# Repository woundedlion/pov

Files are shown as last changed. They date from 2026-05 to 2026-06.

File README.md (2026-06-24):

# Holosphere

### [▶ Play with the live WebAssembly simulator](https://woundedlion.github.io/daydream/)

### [📖 API documentation (Doxygen)](https://woundedlion.github.io/pov/)

---

<p align="center">
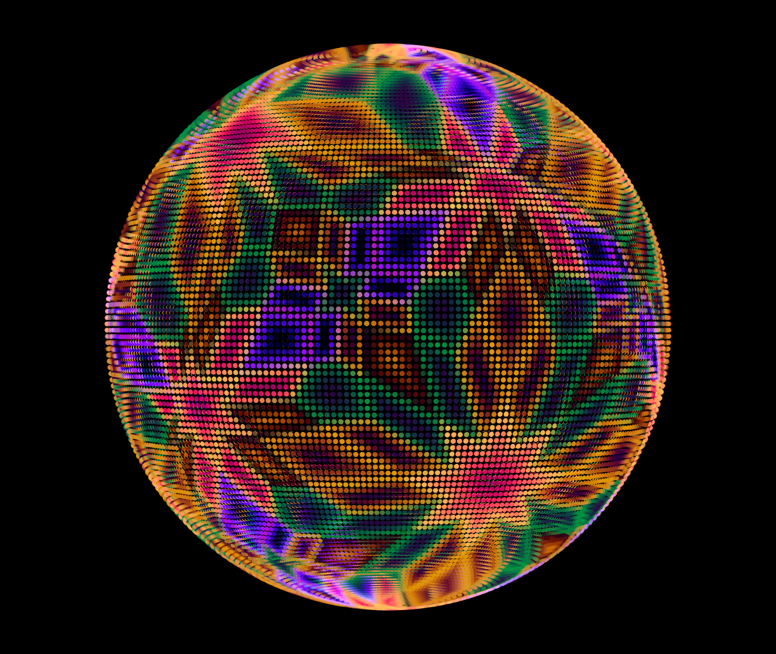
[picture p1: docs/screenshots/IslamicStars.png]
Holosphere — IslamicStars effect
  
</p>

A persistence-of-vision (POV) LED sphere and its real-time simulator. The device spins a strip of LEDs at 480 RPM while a Teensy microcontroller fires pixels at microsecond intervals to paint full-color imagery on the surface of a virtual sphere. The simulator renders the same effects in a browser window at up to 288×144 resolution using the identical C++ code compiled to WebAssembly.

The project spans **two repositories** that ship as one product:

| Repo | Role | What lives here |
|---|---|---|
| [**Holosphere**](https://github.com/woundedlion/pov) | C++ engine + firmware | All rendering code, effects, hardware drivers (`pov_single.h`, `pov_segmented.h`), the Emscripten/WASM target, unit tests, and this README. |
| [**daydream**](https://github.com/woundedlion/daydream) | Web simulator | Three.js renderer, the compiled `holosphere_wasm.{js,wasm}` artifacts (output of Holosphere's WASM build), GUI/sidebar, recorder, segmented-POV Web Workers, and standalone geometry tools. |

Building the WASM target in Holosphere installs `holosphere_wasm.js`, `holosphere_wasm.wasm`, this README, and `docs/screenshots/` into the sibling `daydream/` checkout — so both repos always serve the same README. The live demo is daydream served from GitHub Pages.

---

## Table of Contents

1. [Hardware](#1-hardware)
2. [Engineering Philosophies](#2-engineering-philosophies)
3. [Repository Map](#3-repository-map)
4. [Architecture Overview](#4-architecture-overview)
5. [Data Flow: Frame Lifecycle](#5-data-flow-frame-lifecycle)
6. [The Rendering Pipeline](#6-the-rendering-pipeline)
   - [End-to-End Flow](#end-to-end-flow)
   - [Pipeline Domain Transitions](#pipeline-domain-transitions)
   - [The Canvas](#the-canvas)
   - [The Filter Pipeline](#the-filter-pipeline)
7. [Core Subsystems](#7-core-subsystems)
   - [7.0 The Shader Interface](#70-the-shader-interface)
   - [7.1 SDF Shapes and the Scan Rasterizer](#71-sdf-shapes-sdfh-and-the-scan-rasterizer-scanh)
   - [7.2 The Curve Rasterizer](#72-the-curve-rasterizer-ploth)
   - [7.3 The Animation System](#73-the-animation-system-animationh)
   - [7.4 Geometry Transformers](#74-geometry-transformers-transformersh)
   - [7.5 Memory Architecture](#75-memory-architecture-memoryh-memorycpp)
   - [7.6 The Color System](#76-the-color-system-colorh)
   - [7.7 The Mesh System](#77-the-mesh-system-meshh-conwayh-hankinh-spatialh-solidsh)
   - [7.8 Generators](#78-generators-generatorsh)
   - [7.9 The Preset System](#79-the-preset-system-presetsh)
   - [7.10 Hardware Drivers](#710-hardware-drivers-dma_ledh-pov_singleh-pov_segmentedh)
     - [Frame Sync Protocol: 1-Wire Signal Datasheet](#frame-sync-protocol-1-wire-signal-datasheet)
8. [The Effect System](#8-the-effect-system)
9. [Effects Reference](#9-effects-reference)
10. [The Web Simulator (Daydream)](#10-the-web-simulator-daydream)
    - [10.1 Process and Threading Model](#101-process-and-threading-model)
    - [10.2 The WASM Bridge](#102-the-wasm-bridge)
    - [10.3 The Three.js Renderer](#103-the-threejs-renderer-driverjs)
    - [10.4 Application State](#104-application-state-statejs)
    - [10.5 The Effect Sidebar](#105-the-effect-sidebar-sidebarjs)
    - [10.6 GUI Auto-Generation](#106-gui-auto-generation)
    - [10.7 Segmented POV Workers](#107-segmented-pov-workers-segment_workerjs)
    - [10.8 Vendor Importmap](#108-vendor-importmap-local-first--cdn-fallback)
    - [10.9 Video Recording](#109-video-recording-recorderjs)
    - [10.10 Resolution Presets](#1010-resolution-presets)
    - [10.11 Geometry Tools](#1011-geometry-tools-daydreamtools)
11. [Building](#11-building)

---

## 1. Hardware

Two physical targets share the same rendering engine:

### Holosphere (2015)

| Component | Detail |
|---|---|
| Controller | Teensy 4.0 (600 MHz ARM Cortex-M7) |
| LEDs | 40-pixel addressable strip (20 per half-arm, two-arm rotation) |
| Protocol | SPI via FastLED (WS2801 at 6 MHz) or DMA (HD107S at 12 MHz) |
| Rotation | 480 RPM (8 revolutions/second) |
| Virtual resolution | 96 × 20 |
| Driver | `POVDisplay<40, 480>` in `pov_single.h` |
| Pin assignments | DATA: pin 11, CLOCK: pin 13, RANDOM seed: analog pin 15 |

### Phantasm

| Component | Detail |
|---|---|
| Controllers | 4× Teensy 4.0 (600 MHz ARM Cortex-M7) |
| LEDs | 2 × 144-pixel strips (288 total, 72 per segment) |
| Protocol | DMA (HD107S at 24 MHz) |
| Rotation | 480 RPM (8 revolutions/second), 16 FPS from 2 sides of the ring |
| Virtual resolution | 288 × 144 |
| Driver | `POVSegmented<288, 4, 480>` in `pov_segmented.h` |
| Synchronization | 1-wire: count-coded sync symbols from segment 0 discipline a per-board flywheel timebase (`hardware/pov_sync.h`) |
| Pin assignments | ID: pins 21–22, Sync symbols: pin 3 (out, segment 0) / pin 4 (in), SPI: pins 11 + 13 |

The POV effect works because each revolution takes ~125 ms and a new column is painted every `1,000,000 / (RPM/60) / width` microseconds (on Holosphere the IntervalTimer ISR advances one column per fire; on Phantasm each board's flywheel ISR derives the column from the CPU cycle counter — see §7.10). The LED strip is mounted on both sides of a rotating arm: the top half of the strip handles one hemisphere and the bottom half handles the opposite hemisphere, so one full revolution paints a complete sphere.

---

## 2. Engineering Philosophies

The five design decisions below account for much of the engine's structure; the rest of the document assumes them.

### Why 16-bit Linear Color?

Most LED art codebases use gamma-corrected 8-bit values throughout and blend in sRGB space. This produces muddy mixes: red + blue = dark purple instead of magenta. Holosphere blends in linear light (16-bit precision), then gamma-encodes only at the hardware output. The improvement is most visible in soft gradients and multi-layer alpha compositing. Palette interpolation goes a step further into the OKLCH perceptual color space, with shortest-arc hue interpolation that avoids the red→green→blue detour.

### Why Compile-Time Resolution?

Templating on `<W, H>` means every pixel coordinate transform, bounding box computation, and LUT index is resolved at compile time. The hardware target `<96, 20>` runs with no runtime overhead from generality. The simulator builds separate specializations for `<288, 144>`. Each supported resolution is a separate instantiation, so binary size increases in exchange.

### Why Arena Allocation?

The Teensy heap fragments under heavy mesh subdivision. The single-block partitioned arena design (persistent + scratch A + scratch B, 335 KB total) gives deterministic memory behavior: persistent data allocated once and kept; scratch data RAII-scoped to the function that needed it. The `configure_arenas()` function allows effects to repartition the fixed block based on their needs — mesh-heavy effects can claim more persistent space, while subdivision-heavy effects can expand their scratch pools. All functions take explicit `Arena&` parameters — Conway operators take `(Arena& target, Arena& temp)`, generators take `(Arena& a, Arena& b)` — so the memory layout during heavy geometric operations is explicit at every call site, with no hidden state or implicit arena references.

### Why the ISR Double Buffer?

POV display requires pixel data to be ready before each column interval fires — roughly 434 µs to 1.3 ms depending on resolution at 480 RPM (the per-column period is `1,000,000 / (RPM/60) / W` µs, i.e. ~434 µs for Phantasm's 288 columns and ~1302 µs for Holosphere's 96). A naive approach (rendering in the ISR) would block the main loop. Instead, the main loop renders freely into a back buffer while the ISR reads from a separate front buffer. `queue_frame()` / `advance_display()` synchronize with minimal interrupt-disabled critical sections.

### Why Fail-Fast (`HS_CHECK`)?

On hardware there is no debugger attached and no console to read — a corrupted arena that ships garbage to the LEDs is the worst possible outcome, because the failure is silent and the cause is already gone by the time it shows on the sphere. So invariant violations *trap at the violation site* rather than being masked by bounded fallbacks. `HS_CHECK(cond)` (`platform.h`) compiles to a single predicted-not-taken branch to `__builtin_trap()` and, unlike `assert()`, is **not** stripped by `NDEBUG` — it still fires in the optimized device build, where `NDEBUG` is defined only to keep newlib's `__assert_func`→`fprintf` (and all of stdio) out of the image. It pulls in no stdio of its own.

The rule is deliberate about *where* it goes: `HS_CHECK` guards **cold** paths only — container growth, arena OOM, capacity and bounds guards at allocation/registration/config seams — where a violation is a logic or sizing bug with no valid recovery. It is never placed in the per-pixel hot loop; hot paths that need a check use a stripped `assert` backed by a cold trap at the corresponding bind/setup site. Genuinely *transient* conditions (a DMA overrun, a dropped frame) are not invariant violations and get bounded/soft handling instead. The native test suite includes a death harness that asserts these traps actually fire (`SIGILL` / `STATUS_ILLEGAL_INSTRUCTION`), so the safety net is verified rather than assumed.

### Coordinate Conventions

- **Y-up Cartesian**: `Vector(x, y, z)` — `y` is the vertical axis
- **Spherical**: `theta` = azimuth (longitude), `phi` = polar angle from +Y (co-latitude)
- **Pixel mapping**: `x ∈ [0, W)` → `theta ∈ [0, 2π)`, `y ∈ [0, H)` → `phi ∈ [0, π]`
- **SDF distances**: in radians on the unit sphere (matching `angle_between()`)
- All geometry LUTs (`PhiLUT<H>`, `TrigLUT<W,H>`) are pre-computed eagerly via `init_geometry_luts()` at engine setup

```
   Side view (looking down −Z):          Top view (looking down −Y):

         +Y (φ=0, north pole)                   +Z (θ=π/2)
          │                                      │
          │  ╱ point P                           │
          │ ╱φ                                   │  ╱ point P
          │╱                                    │ ╱θ
  ────────●────────  equator (φ=π/2)    ────────●────────  +X (θ=0)
          │                                      │
          │                                      │
         −Y (φ=π, south pole)                   −Z (θ=3π/2)

   Pixel canvas → sphere:
      x ∈ [0, W)  →  θ ∈ [0, 2π)    column wraps around the equator (x=0 at +X)
      y ∈ [0, H)  →  φ ∈ [0, π]     row descends from north pole (y=0) to south pole
```

---

## 3. Repository Map

### Holosphere (engine + firmware)

```
├── core/                       Rendering engine
│   ├── platform.h              Arduino vs. WASM vs. Desktop abstraction layer
│   ├── constants.h             MAX_W, MAX_H + ClipRegion segment clip rectangle
│   ├── canvas.h                Effect base class + Canvas RAII write-buffer guard
│   ├── engine.h                Engine API umbrella — included by every effect
│   ├── effects.h               Effect roster (includes each effect + HS_EFFECT_LIST)
│   ├── effects_legacy.h        Pre-engine effects (TheMatrix, Spirals, etc.)
│   ├── effect_registry.h       Self-registering factory: REGISTER_EFFECT macro
│   ├── led.h                   LED pin constants + color-correction RAII guards (driver in hardware/pov_single.h)
│   │
│   ├── 3dmath.h                Vector, Quaternion, Spherical, Complex, Möbius math
│   ├── geometry.h              Fragment, Dots/Points, PhiLUT/TrigLUT, coord conversions
│   ├── color.h                 Pixel16 (16-bit linear), Color4, blend helpers, palettes
│   ├── palettes.h              Named ProceduralPalette instances + shared MeshPaletteBank
│   ├── color_luts.h            Precomputed sRGB ↔ linear LUTs
│   │
│   ├── concepts.h              FunctionRef/Fn callable wrappers, PipelineRef type erasure, Tweenable concept
│   ├── filter.h                Composable render pipeline + all Filter::World/Screen/Pix
│   ├── sdf.h                   SDF shape primitives, CSG operations, distance queries
│   ├── scan.h                  Rasterization primitives (Ring, Circle, Star, Mesh, etc.)
│   ├── plot.h                  Line/curve rasterizer with geodesic/planar strategies
│   ├── animation.h             Timeline, all Animation:: types, ParticleSystem
│   ├── transformers.h          Ripple, Noise, Möbius warp geometry transformers
│   ├── easing.h                Easing functions (cubic, sine, elastic, expo, etc.)
│   ├── waves.h                 sin_wave / tri_wave / square_wave generators
│   │
│   ├── memory.h / memory.cpp   Arena allocator, ScratchScope, Persist<T>
│   ├── mesh.h                  PolyMesh, HalfEdgeMesh, MeshOps (compile, clone, etc.)
│   ├── conway.h                Conway operators (dual, kis, ambo, truncate, etc.)
│   ├── hankin.h                Hankin pattern compilation and update system
│   ├── solids.h                Platonic + Archimedean + Catalan + Islamic solid registry
│   ├── spatial.h               KDTree, k-nearest-neighbor, MeshState (+ speculative AABB)
│   ├── static_circular_buffer.h Fixed-capacity non-allocating circular buffer
│   ├── rotate.h                Quaternion projection helpers
│   ├── generators.h            Universal generate() wrapper for procedural geometry
│   ├── presets.h               Generic Presets<Params, Size> template
│   ├── styles.h                Feedback::Style named presets + space/color transform functions
│   ├── util.h                  wrap(), fast_wrap(), shortest/fwd_distance, apply_if_changed
│   ├── reaction_graph.h/.cpp   Precomputed Fibonacci-lattice K-NN graph (90 KB / 92,160-byte table)
│   ├── FastNoiseLite.h         Third-party: single-header noise library
│   └── FastNoiseLite_config.h  FastNoiseLite build configuration
│
├── effects/                    27 effects (28 headers incl. the shared ReactionDiffusionBase.h):
│                                BZReactionDiffusion.h, HopfFibration.h, IslamicStars.h,
│                                Raymarch.h, … — see §9 Effects Reference
│
├── hardware/                   Hardware drivers
│   ├── dma_led.h               Non-blocking DMA LED controller for HD107S (Teensy 4.x)
│   ├── hd107s_frame.h          HD107S protocol buffer + inline color correction (host-testable)
│   ├── pov_segment_map.h       Pure segment index math (host-testable)
│   ├── pov_single.h            Single-Teensy POV driver (Holosphere)
│   ├── pov_sync.h              Phantasm sync protocol core: flywheel timebase, symbol codec, epoch/beacon (host-testable)
│   └── pov_segmented.h         Multi-Teensy segmented POV driver (Phantasm)
│
├── targets/                    Per-target entry points
│   ├── Holosphere/
│   │   └── Holosphere.ino      Holosphere entry — NUM_PIXELS=40, RPM=480
│   ├── Phantasm/
│   │   └── Phantasm.ino        Phantasm entry — 4×Teensy, TOTAL_PIXELS=288, RPM=480
│   └── wasm/
│       ├── wasm.cpp            Emscripten bindings — HolosphereEngine JS class
│       └── param_marshal.h     Pure parameter definition/value marshaling, single ordering source (host-testable)
│
├── CMakeLists.txt              Emscripten build (outputs holosphere_wasm.js + .wasm)
├── tests/                      Unit tests (CMake subdirectory)
├── scripts/                    Build + CI tooling
│   ├── generate_luts.py        sRGB ↔ linear LUT generator of record (emits core/color_luts.h)
│   ├── wasm_smoke.mjs          Runtime WASM smoke: drives every effect at both resolutions (CI)
│   └── capture_screenshots.mjs Headless gallery capture for docs/screenshots/
└── justfile                    Task runner: `just build` / `build-debug` / `test` / `install`
```

### daydream (web simulator)

```
├── index.html                  Main simulator page
├── vendor-importmap.js         Local-first / CDN-fallback importmap helper
├── holosphere_wasm.js          Installed from Holosphere's WASM build
├── holosphere_wasm.wasm        Installed from Holosphere's WASM build
├── README.md                   Installed from Holosphere (this file)
├── docs/screenshots/           Installed from Holosphere
│
├── daydream.js                 App entry: WASM loader, state wiring, GUI/sidebar
├── driver.js                   Three.js scene: sphere mesh, dots, OrbitControls,
│                                  axes overlay, picture-in-picture camera, resize
├── geometry.js                 Sphere-pixel position math (pixelToVector, etc.)
├── state.js                    AppState (pub/sub) + URLSync (query-string mirror)
├── gui.js                      lil-gui wrapper used by the main page and tools
├── sidebar.js                  Effect list + sort + keyboard navigation
├── recorder.js                 MediaRecorder pipeline (mp4 / webm), sim-synced
├── segment_controller.js       Orchestrates the segmented-POV worker pool:
│                                  dispatch, generation fence, and compositing
├── segment_worker.js           Web Worker that hosts one WASM instance per
│                                  Phantasm hardware segment (parallel render)
├── segment_layout.js           Pure segment-layout math (Node-unit-testable, no WASM/Worker)
├── worker_protocol.js          JSDoc @typedef contract for main↔worker messages (no runtime code)
├── styles/                     CSS for the main page and tools
│
├── tools/                      Standalone geometry tools (own HTML pages)
│   ├── lissajous.html          Spherical Lissajous curve designer
│   ├── mobius.html             Möbius transformation visualizer
│   ├── palettes.html           Procedural palette tuner
│   ├── solids.html             Conway operator playground (uses MeshOps bridge)
│   └── splines.html            Catmull-Rom spline designer
│
├── three.js/                   Optional vendored Three.js checkout
├── node_modules/lil-gui/       Optional local lil-gui (npm install)
└── package.json
```

When the local `three.js/` and `node_modules/lil-gui/` directories are absent (e.g. on the GitHub Pages deploy, and by default), [`vendor-importmap.js`](https://github.com/woundedlion/daydream/blob/master/vendor-importmap.js) resolves libraries from jsdelivr; `npm run importmap:local` switches it to the vendored copies for offline dev. See [§10.8](#108-vendor-importmap-local-first--cdn-fallback).

---

## 4. Architecture Overview

Three build targets share a common engine:

```
┌──────────────────────────────────────────────────────────────────────────┐
│                            C++ Codebase                                 │
│                                                                         │
│  ┌──────────────┐   ┌──────────────────────────────────────────────┐    │
│  │   targets/   │   │          core/  (Rendering Engine)           │    │
│  │              │   │                                              │    │
│  │ Holosphere/  │   │  Effects → Canvas → Filter Pipeline          │    │
│  │  .ino        │   │      → SDF/Plot → Pixel Buffer               │    │
│  │              │   │                                              │    │
│  │ Phantasm/    │   │  effects/  (27 visual algorithms)            │    │
│  │  .ino        │   │                                              │    │
│  │              │   ├──────────────────────────────────────────────┤    │
│  │ wasm/        │   │          hardware/  (Drivers)                │    │
│  │  wasm.cpp   │   │  pov_single.h — single-Teensy POV            │    │
│  │              │   │  pov_segmented.h — multi-Teensy segmented POV │    │
│  │              │   │  dma_led.h — HD107S DMA SPI pipeline          │    │
│  └──────┬───────┘   └──────────────────────────────────────────────┘    │
│         │                              ↑                                │
└─────────┼──────────────────────────────┼────────────────────────────────┘
          │                              │
   ┌──────┴──────┐              ┌────────┴────────┐
   │  Teensy 4.x │              │   Emscripten    │
   │  ISR + DMA  │              │   WASM build    │
   │  480 RPM    │              │                 │
   └──────┬──────┘              └────────┬────────┘
    Physical LED strip            daydream/
    (Holosphere/Phantasm)         Three.js + WASM
```

### Compile-Time Resolution Parameterization

Every rendering-related class is templated on `<int W, int H>`:

```cpp
template <int W, int H> class HopfFibration : public Effect { ... };
template <int W, int H, typename... Filters> struct Pipeline { ... };
```

This means the compiler generates fully specialized, zero-overhead versions of the entire pipeline for each supported resolution. The original Holosphere runs `<96, 20>` (96 columns × 20 rows). The new art piece runs `<288, 144>`. The simulator supports both resolutions.

The `platform.h` header abstracts all target-specific differences:

| Symbol | Arduino/Teensy | WASM/Desktop |
|---|---|---|
| `DMAMEM` | Teensy DMA-accessible RAM segment | No-op macro |
| `hs::log()` | `Serial.println()` | `vprintf`/`printf` |
| `hs::millis()` | `::millis()` | `std::chrono` |
| `hs::rand_f()` | `Pcg32(1337)` | `Pcg32(1337)` |
| `hs::disable_interrupts()` | `noInterrupts()` | No-op |
| `CRGB`, `CHSV` | FastLED types | Struct mocks |

---

## 5. Data Flow: Frame Lifecycle

### Hardware Path

```
Main Loop (draw_frame)                    ISR (show_col, fires every N µs)
─────────────────────────────────         ─────────────────────────────────
                                          Timer fires at column interval
POVDisplay<S,RPM>::show<Effect>()
  IntervalTimer::begin(show_col, interval)

  effect->draw_frame():
    Canvas canvas(*effect)               ISR reads from bufs_[prev_]
      ↓ advance_buffer()                 for y in 0..S/2:
      ↓ (copies prev if persist_pixels)    leds[S/2 - y - 1] = get_pixel(x, y)
      ↓                                    leds[S/2 + y]     = get_pixel(x±W/2, y)
    [effect renders to bufs_[cur_]]
      ↓                                  FastLED.show()
    ~Canvas():                           if strobe_columns(): FastLED.showColor(black)
      queue_frame()                      x = (x+1) % width
      ↓ next_ = cur_ (interrupt-safe)    if x==0 || x==width/2:
                                           advance_display()  (prev_ = next_)
                                           [new frame begins displaying]
```

Three `std::atomic<int>` indices manage the double buffer:

| Index | Role |
|---|---|
| `cur_` | Which buffer the main loop is currently writing |
| `next_` | The last completed frame (queued by `queue_frame()`) |
| `prev_` | The frame the ISR is currently reading |

The ISR never touches `cur_`. The main loop atomically updates `next_` inside `queue_frame()` with interrupts disabled. `advance_display()` is called by the ISR at every half-revolution to flip `prev_` to `next_`.

The two framebuffers are placed in Teensy DMAMEM (OCRAM) for capacity — at `MAX_W * MAX_H` 16-bit pixels they are far too large for the tightly-coupled DTCM that holds the stack and hot data. They are software render targets, read by the ISR and packed into the LED controller's protocol frame; they are never DMA'd themselves (the eDMA TX buffer is `HD107SFrame::buffer_`, in the controller, which is the buffer that actually clocks out over SPI):

```cpp
static DMAMEM Pixel buffer_a[MAX_W * MAX_H];
static DMAMEM Pixel buffer_b[MAX_W * MAX_H];
```

### WASM Path

In the simulator there is no ISR. `HolosphereEngine::drawFrame()` calls `draw_frame()` then `advance_display()` directly. The pixel buffer is a flat 16-bit array that is read back by JavaScript as a zero-copy `typed_memory_view`:

```
C++: wasmEngine.drawFrame()
       → currentEffect->draw_frame()
       → currentEffect->advance_display()
       → copy Pixel(r,g,b) into pixelBuffer as uint16_t triples

JS:  wasmEngine.getPixels()
       → Uint16Array view into WASM linear memory (no copy)
       → bound as the instanced dot-mesh's `instanceColor` attribute, declared
         `normalized` so the GPU scales 0–65535 → 0–1 (no JS-side divide)
       → WebGL renderer
```

---

## 6. The Rendering Pipeline

### End-to-End Flow

A typical effect frame follows a four-stage pipeline. Not every effect uses every stage — some skip generation entirely, others skip transformations, and a few full-screen shader effects (e.g. Liquid2D, Flyby, Raymarch) extend `Effect` directly and bypass the filter pipeline altogether — but the available primitives compose along this flow:

```
┌─────────────┐     ┌──────────────┐     ┌──────────────┐     ┌──────────────┐
│  Generate   │     │  Transform   │     │  Rasterize   │     │   Filter     │
│             │ ──▸ │              │ ──▸ │              │ ──▸ │   Pipeline   │
│ geometry.h  │     │transformers.h│     │ sdf.h/scan.h │     │  filter.h    │
│ solids.h    │     │              │     │ plot.h       │     │              │
│ generators.h│     │              │     │              │     │              │
└─────────────┘     └──────────────┘     └──────────────┘     └──────────────┘

  Solids::get()      MeshOps::transform    Scan::Mesh::draw     Pipeline<W,H,
  MeshOps::hankin    RippleTransformer      Scan::Ring::draw       Orient,
  generate(arena,fn) NoiseTransformer       Plot::SplineChain      AntiAlias,
  ParticleSystem     OrientTransformer      Scan::Shader::draw     Feedback>
```

**Generate**: Create or update geometry — mesh from the solids registry, Hankin pattern compilation, Fibonacci lattice for reaction-diffusion, or particle positions from physics. The `generate()` wrapper manages arena lifecycle.

**Transform**: Deform geometry in world space — ripple wavelets, noise displacement, Möbius warps, quaternion rotation. `MeshOps::transform()` chains transformers: `transform(input, output, arena, ripple, orient)`.

**Rasterize**: Convert geometry to pixels. Two families:
- **SDF path** (`sdf.h` → `scan.h`): analytic shapes with scanline intervals and `quintic_kernel` anti-aliasing
- **Plot path** (`plot.h`): line/curve rasterization with adaptive step size scaled by `sin(φ)` for uniform sampling
- **Shader path** (`Scan::Shader`): full-screen per-pixel evaluation with optional SSAA

**Filter**: The `Pipeline<W, H, Filters...>` variadic template processes each plotted point through a chain of filter stages before it reaches the canvas.

### Pipeline Domain Transitions

The filter pipeline operates across three coordinate domains. Each filter declares which domain it works in, and the pipeline automatically converts between them at compile time:

```
          World Space                Screen Space             Pixel Space
     (3D unit-sphere vectors)     (fractional x, y)       (integer x, y)
    ┌──────────────────────┐    ┌─────────────────┐    ┌─────────────────┐
    │ World::Orient        │    │ Screen::AntiAlias│    │ Pixel::Feedback │
    │ World::Trails        │──▸ │ Screen::Blur     │──▸ │ Pixel::Chromatic│
    │ World::Replicate     │    │ Screen::Trails   │    │   Shift         │
    │ World::Mobius        │    │                  │    │                 │
    │ World::Hole          │    │                  │    │                 │
    └──────────────────────┘    └─────────────────┘    └─────────────────┘
    Coordinate: Vector(x,y,z)   Coordinate: float x,y   Coordinate: int x,y

         vector_to_pixel() ──▸         floor/clamp ──▸
    ◂── pixel_to_vector()         ◂── expand to float
```

**World → Screen**: `vector_to_pixel()` projects a 3D unit-sphere vector to fractional pixel coordinates via `(theta / 2π * W, phi / π * H)`.

**Screen → Pixel**: `AntiAlias` distributes the fractional coordinate to its 4 nearest integer pixels using `quintic_kernel` bilinear weights, with `sin(φ)` density compensation.

**Pixel → Canvas**: The base `Pipeline<W,H>` (the identity terminal) composites the final color into `canvas(x, y)` with straight-alpha (`src * α + dst * (1-α)`) in linear light.

**World filters** operate on the 3D vector before projection — they can rotate, replicate, or warp geometry in spherical coordinates without loss. **Screen filters** operate after projection but before integer snapping — they distribute sub-pixel energy for anti-aliasing and blur. **Pixel filters** operate per-frame on the full canvas — feedback and chromatic aberration read from the previous frame buffer.

### The Canvas

`Canvas` is a RAII scope guard for one frame of rendering. Constructing it acquires the next write buffer; destroying it queues the finished frame for display.

```cpp
void MyEffect::draw_frame() override {
    Canvas canvas(*this);   // advance_buffer() — grab write buffer
                            // clear buffer if !persist_pixels
    // ... render here using canvas(x, y) = pixel ...
}                           // ~Canvas() — queue_frame()
```

`canvas(x, y)` is a direct array subscript into the write buffer (`bufs_[cur_][y * width + x]`). No bounds checking, no virtual dispatch.

### The Filter Pipeline

The **filter pipeline** is a variadic template that chains filter stages:

```cpp
Pipeline<W, H,
    Filter::World::Trails<W, MAX_ITEMS>,   // 3D world-space trail decay
    Filter::World::Orient<W>,              // quaternion rotation + motion blur
    Filter::Screen::AntiAlias<W, H>        // bilinear sub-pixel AA
> filters;
```

`Pipeline<W, H, Filters...>` is a recursive template that chains filter stages. Each stage receives a `plot()` call and can transform it before forwarding downstream:

```
filters.plot(canvas, world_position, color, age, alpha)
    → World::Trails: store for later decay, pass through
    → World::Orient: rotate by current quaternion, adjust age
    → Screen::AntiAlias: distribute to 4 nearest pixels
    → Pipeline<W,H> (base): vector_to_pixel → canvas(x,y) = blend(color, alpha)
```

The pipeline handles the 3D/2D coordinate mismatch automatically at compile time: if a 3D filter receives a 2D coordinate it lifts it via `pixel_to_vector`; if a 2D filter receives a 3D vector it projects via `vector_to_pixel`.

#### World-Space Filters

| Filter | Effect |
|---|---|
| `World::Orient<W>` | Rotates every incoming 3D point by the current `Orientation` quaternion. Uses the orientation history to distribute motion-blur age values across a SLERP-interpolated sweep. |
| `World::Trails<W, Capacity>` | Stores world-space points in an arena-allocated ring buffer with a TTL countdown. On `flush()`, re-draws aged points through a `TrailFn` color function. Trail items are quantized to 8 bytes each (int16 xyz + uint8 TTL). |
| `World::Replicate<W>` | Clones geometry N times around the Y-axis by re-plotting each point rotated by `2π/N`. |
| `World::VertexReplicate<W, N>` | Replicates geometry onto the N vertices of a solid by precomputing rotation quaternions from vertex[0] to each other vertex. |
| `World::Mobius<W>` | Applies a Möbius transformation via stereographic projection: sphere → complex plane → Möbius(z) → back to sphere. |
| `World::Hole<W>` | Masks out a spherical cap by attenuating points within a radius via quintic falloff. Supports both by-value and by-reference origin (`HoleRef<W>`). |
| `World::OrientSlice<W>` | Selects from a list of orientations based on each point's projection along an axis — enables per-hemisphere rotation effects. |

#### Screen-Space Filters

| Filter | Effect |
|---|---|
| `Screen::AntiAlias<W,H>` | Distributes a sub-pixel coordinate to its 4 nearest integer pixels using `quintic_kernel` bilinear weights, eased uniformly on both axes in framebuffer space — no `sin(φ)` density compensation, because anti-aliasing is a property of the pixel grid, not of where the columns map on the sphere. |
| `Screen::Blur<W, H>` | Applies a parameterized 3×3 Gaussian convolution kernel at plot time. |
| `Screen::Trails<W, MAX_PIXELS>` | Screen-space variant of trail decay; stores 2D coordinates with TTL and redraws via a trail color function. Uses arena-allocated storage (`MAX_PIXELS` capacity, default 1024). |

#### Pixel-Space Filters

| Filter | Effect |
|---|---|
| `Pixel::Feedback<W, H>` | Style-driven full-screen feedback loop. During `flush()` iterates the full canvas, samples the previous frame from the Canvas front buffer with bilinear interpolation, applies the bound `Feedback::Style`'s spatial transform and color transform with fade, then blends into the back buffer. Stateless — uses Canvas double-buffering, no internal frame storage. The warp field is computed on a coarse `W/DS × H/DS` grid (scratch-arena allocated) and bilinearly upsampled; `DS = style.downsample`. See `Feedback::Style` below for preset selection. |
| `Pixel::ChromaticShift<W>` | Splits a pixel into R, G, B channels and offsets them by 1–3 pixels horizontally to simulate chromatic aberration. |

#### Feedback Styles (`styles.h`)

`Feedback::Style` bundles spatial transform, color transform, and scalar parameters into a single POD-copyable struct with named presets. `Filter::Pixel::Feedback<W,H>` (see Pixel-Space Filters above) takes a `Style&` directly — no template parameters for transform types, no adapter boilerplate.

```cpp
// Declare a style member and use it in the pipeline:
Feedback::Style style = Feedback::Style::Smoke();
Pipeline<W, H, Filter::World::Orient<W>, Filter::Screen::AntiAlias<W, H>,
         Filter::Pixel::Feedback<W, H>> filters(
    ..., Filter::Pixel::Feedback<W, H>(style));
```

The Filter auto-syncs from the Style every frame — when the Style lerps between presets, the function pointers snap at the midpoint while scalars interpolate smoothly.

| Preset | Description |
|---|---|
| `Style::Churn()` | Dense fine-grain turbulence with strong hue shift. Tight scale, slow drift. |
| `Style::Smoke()` | Gentle drifting haze with slow noise. Classic smoke look. |
| `Style::Frozen()` | Static frozen distortion — no temporal movement. |
| `Style::Shatter()` | Extreme static warping with fast decay. Shattering glass look. |
| `Style::Drift()` | Flowing medium-strength distortion. Gentle liquid drift. |
| `Style::Melting()` | Image melts and drips downward off the sphere. |
| `Style::Swirling()` | Fast downward swirl with strong distortion, no hue shift. |

Available transform functions:

| Space Transform | Description |
|---|---|
| `Feedback::noise_warp` (default) | 3D simplex noise distortion via `noise_transform()` |
| `Feedback::melt_warp` | Downward melt — slerps samples toward the north pole (image drips south) plus noise wobble |
| `Feedback::identity_warp` | No spatial distortion (pass-through) |

| Color Transform | Description |
|---|---|
| `Feedback::hue_fade` (default) | Multiplies by fade, then rotates hue by `style.hue_shift` |
| `Feedback::plain_fade` | Multiplies by fade only — no color shift |

Custom presets can use any function matching the `Feedback::SpaceFn` / `Feedback::ColorFn` signatures.

#### Combining Filters

Filters compose freely. The order matters — world-space filters must precede screen-space filters if both are present. Some common combinations:

```cpp
// Rotating geometry with anti-aliasing
Pipeline<W, H, Filter::World::Orient<W>, Filter::Screen::AntiAlias<W, H>>

// Particle trails in world space with orientation
Pipeline<W, H,
    Filter::World::Trails<W, 50000>,
    Filter::World::Orient<W>,
    Filter::Screen::AntiAlias<W, H>>

// Orientation + anti-aliasing + feedback with Smoke style
Pipeline<W, H,
    Filter::World::Orient<W>,
    Filter::Screen::AntiAlias<W, H>,
    Filter::Pixel::Feedback<W, H>>
```

---

## 7. Core Subsystems

### 7.0 The Shader Interface

All rasterizers — SDF scanline, curve plotting, mesh, volumetric, and full-screen shader — share a common shading model based on the `Fragment` struct and two function signatures.

#### The Fragment

A `Fragment` (`geometry.h`) is the data packet exchanged between rasterizers and shaders. It carries the pixel position, four general-purpose float registers, and the output color:

```cpp
struct Fragment {
  Vector pos;              // Position (typically a unit vector on the sphere)
  float v0 = 0.0f;        // Register 0: normalized progress t (0–1)
  float v1 = 0.0f;        // Register 1: arc length / distance
  float v2 = 0.0f;        // Register 2: index / face ID
  float v3 = 0.0f;        // Register 3: auxiliary
  float size = 1.0f;      // Size metric for normalization
  float age = 0.0f;       // Age (for trail decay / motion blur)
  Color4 color = Color4(0, 0, 0, 0); // Output: shader writes RGBA here; defaults to transparent black (Color4()'s default is opaque)
};
```

The registers are *inputs* — populated by the rasterizer before the shader runs. The shader reads them and writes `color`. The rasterizer then forwards the color through the filter pipeline to the canvas.

#### Shader Signatures

Two shader types are defined as zero-allocation `FunctionRef` callables (`concepts.h`):

| Signature | Type | Role |
|---|---|---|
| `FragmentShaderFn` | `void(const Vector &, Fragment &)` | Per-pixel/per-sample shader. Receives the world position and a pre-populated Fragment; writes `color`. Called for every rasterized point. |
| `VertexShaderFn` | `void(Fragment &)` | Per-vertex or per-pixel-center shader. Runs once before sub-sampling to set up expensive shared state in the Fragment registers. Optional. |

`FunctionRef` is a non-owning, non-allocating type-erased callable (similar to `std::function_ref` from C++26). It captures a pointer to any lambda, functor, or function pointer with zero heap allocation — critical for ISR-safe code on Teensy.

Effects pass lambdas that capture their state:

```cpp
auto shader = [&](const Vector &p, Fragment &f) {
    float t = f.v0;           // read: normalized progress from rasterizer
    f.color = palette.get(t); // write: color from palette lookup
};
Scan::Ring::draw<W, H>(pipeline, canvas, basis, radius, thickness, shader);
```

#### Register Conventions by Rasterizer

Each rasterizer family populates the Fragment registers with a consistent convention. Shaders can rely on these semantics:

**SDF Scanline Path** (`Scan::Ring`, `Scan::Star`, `Scan::PlanarPolygon`, `Scan::Flower`, `Scan::Line`, `Scan::Mesh`):

| Register | Source | Meaning |
|---|---|---|
| `v0` | `DistanceResult.t` | Normalized parameter (0–1) — azimuthal angle for rings, perimeter progress for polygons |
| `v1` | `DistanceResult.raw_dist` | Unsigned distance to shape centerline (for distance-based effects) |
| `v2` | Set by rasterizer | Face index for `Scan::Mesh` (0 otherwise) |
| `v3` | `DistanceResult.aux` | Auxiliary — shape-dependent secondary parameter (0 when unused, including faces) |
| `size` | `DistanceResult.size` | Shape radius or apothem for normalization |

The `DistanceResult` struct is returned by each SDF shape's `distance<ComputeUVs>()` method:

```cpp
struct DistanceResult {
  float dist;        // Signed distance (negative = inside)
  float t;           // Normalized parameter (0–1)
  float raw_dist;    // Unsigned / supplementary distance
  float aux;         // Auxiliary (barycentric, etc.)
  float size = 1.0f; // Size metric
};
```

**Curve Plot Path** (`Plot::Line`, `Plot::Multiline`, `Plot::Ring`, `Plot::PlanarPolygon`, `Plot::SplineChain`, `Plot::Bezier`):

| Register | Meaning |
|---|---|
| `v0` | Path progress (0.0 → 1.0 along the full curve) |
| `v1` | Cumulative arc length in radians |
| `v2` | Vertex index (integer cast to float) |
| `v3` | Inherited from control-point Fragment (user-defined) |

Plot primitives interpolate registers between control-point Fragments via `Fragment::lerp()`. The vertex shader, if provided, runs once per control point before rasterization. For the always-planar primitives (`Plot::PlanarPolygon`, `Plot::Star`, `Plot::Flower`) the rasterizer re-derives `v0`/`v1` from the rendered azimuthal-equidistant arc — which bows longer than the great-circle chord between vertices — so both stay consistent with the drawn position.

**Full-Screen Shader Path** (`Scan::Shader`):

Registers are not pre-populated — the shader receives only `pos` (reconstructed from pixel coordinates). The single-callback overload provides a `Color4(const Vector &)` interface. The two-callback overload separates per-pixel vertex setup from per-subsample fragment evaluation.

**Volumetric Path** (`Scan::Volume`):

The fragment shader receives `pos` set to the closest local-space hit point (in the SDF's coordinate frame) and `size` set to the closest signed distance. No register convention — the shader computes lighting from the local-space position directly.

### 7.1 SDF Shapes (`sdf.h`) and the Scan Rasterizer (`scan.h`)

The rendering pipeline splits shape definitions from rasterization. `sdf.h` defines the SDF shape primitives, each implementing three methods:

1. **`get_vertical_bounds()`** — analytic tight bounding box in pixel-Y space (phi angle range). Only rows within this range are scanned.
2. **`get_horizontal_intervals(y, out)`** — analytic scanline intervals per row. Called per row to skip empty columns without evaluating the distance function.
3. **`distance<ComputeUVs>(p, result)`** — signed distance from a sphere-surface point `p` to the shape boundary, plus texture coordinate and auxiliary data in `DistanceResult`.

`scan.h` contains `Scan::rasterize()`, which drives the scanline loop and anti-aliasing, plus convenience wrappers that pair SDF shapes with the rasterizer.

The `process_pixel` function applies anti-aliasing based on shape type:
- **Solid shapes**: quintic smoothstep over a 1-pixel AA border. Full interior pixels (`d < -pixel_width`) skip AA math entirely.
- **Strokes**: opacity falloff across the full stroke thickness.

#### SDF Shape Primitives (`sdf.h`)

| Shape | Description |
|---|---|
| `SDF::Ring` | Geodesic circle at a given radius and thickness |
| `SDF::DistortedRing` | Ring with per-azimuth radius perturbation via a callback |
| `SDF::PlanarPolygon` | Regular N-gon in the tangent plane of a basis vector |
| `SDF::SphericalPolygon` | Regular N-gon with geodesic (great-circle) edges |
| `SDF::Star` | N-pointed star using the standard inradius/circumradius construction |
| `SDF::Flower` | Inverted star (N-petal flower shape from the antipodal perspective) |
| `SDF::Line` | Geodesic line segment between two sphere-surface points |
| `SDF::Face` | Planar polygon face (used for mesh rendering) |
| `SDF::Torus` | 3D volumetric torus SDF with configurable major/minor radii (Cartesian ray-space, not a 2D sphere-surface shape) |
| `SDF::Warp::Twist` | Domain warp composed with a volumetric SDF via `SDF::WarpedVolume<Shape, Warp>` — e.g. `WarpedVolume<Torus, Warp::Twist>` twists a torus by oscillating Y around the ring azimuth, with an analytic Lipschitz bound for safe sphere-tracing (used by Raymarch) |

#### CSG Operations (`sdf.h`)

Shapes can be combined using Constructive Solid Geometry:

```cpp
SDF::Union<Ring, PlanarPolygon>        // min(d_A, d_B)
SDF::SmoothUnion<Ring, PlanarPolygon>  // smooth minimum with blending radius
SDF::Subtract<Ring, PlanarPolygon>     // max(d_A, -d_B)
SDF::Intersection<Ring, PlanarPolygon> // max(d_A, d_B) with interval intersection
SDF::AngularRepeat<Shape>        // N-fold angular repetition around an axis
```

#### Scan Rasterization Primitives (`scan.h`)

Convenience structs that construct an SDF shape and rasterize in a single `draw()` call:

| Primitive | Description |
|---|---|
| `Scan::Ring` | Rasterizes a ring (from `SDF::Ring`) |
| `Scan::Circle` | Filled circle (ring with radius-wide thickness) |
| `Scan::Point` | Thick dot at a sphere-surface position |
| `Scan::Line` | Geodesic line segment between two points |
| `Scan::Star` | N-pointed star shape |
| `Scan::Flower` | N-petal flower shape |
| `Scan::DistortedRing` | Ring with per-azimuth radius perturbation |
| `Scan::PlanarPolygon` | Regular N-gon in the tangent plane |
| `Scan::SphericalPolygon` | Regular N-gon with geodesic (great-circle) edges |
| `Scan::Mesh` | Rasterizes all faces of a `MeshState` or `PolyMesh` |
| `Scan::Shader` | Full-screen per-pixel shader with configurable SSAA (super-sample anti-aliasing). The single-callback overload accepts a fragment shader. The two-callback overload separates a per-pixel vertex shader (called once at pixel center) from a per-subsample fragment shader (called SAMPLES×) — enabling efficient SSAA with expensive per-pixel work computed once (used by BZReactionDiffusion for 4× SSAA). |
| `Scan::TransformedVolume` | Wraps an SDF shape with a world-space position and orientation quaternion for volumetric rendering |
| `Scan::Volume` | Volumetric ray-marcher that steps along the view direction through a `TransformedVolume`, applying a fragment shader at the hit point with configurable step count and AA width |

### 7.2 The Curve Rasterizer (`plot.h`)

For drawing lines, curves, and paths, the `Plot` namespace provides a geodesic/planar rasterizer with adaptive step size. The key insight is that near the poles of the sphere, pixels are much denser in latitude than near the equator. Step size is scaled by `sqrt(1 - y²)` — the sine of the polar angle — so curves remain smooth at all latitudes without over-sampling at the equator.

```cpp
Plot::Line::draw<W, H>(pipeline, canvas, start, end, fragment_shader);
Plot::Bezier::draw<W, H>(pipeline, canvas, p0, p1, p2, p3, fragment_shader);
Plot::SplineChain::draw<W, H>(pipeline, canvas, control_points, tension, shader);
```

All `Plot` primitives accept a `Fragments` array (an arena-backed `ArenaVector<Fragment>`) where each fragment carries position, texture registers (v0–v3), age, and color. Two **independent** axes govern how a path is drawn — do not conflate them:

- **Edge interpolation** — how consecutive fragments are joined. *Geodesic* (the default) walks the great-circle arc between endpoints; *planar* interpolates along an azimuthal-equidistant straight line in a basis's tangent plane (for effects that live in a 2D local space). This is selected by whether a **planar basis** is supplied to the draw call (`null` ⇒ geodesic), **not** by `SplineMode`.
- **Spline evaluation** (`SplineMode`, the spline primitives `Bezier`/`SplineChain` only) — `SplineMode::Geodesic` (the default) samples control points with spherical, slerp-based cubic interpolation; `SplineMode::Fast` uses a cheaper polynomial-then-normalize approximation that distorts on long arcs. `SplineMode` has only `Fast` and `Geodesic` — there is no `SplineMode::Planar`, and it does not control edge interpolation.

#### Plot Primitives

| Primitive | Description |
|---|---|
| `Plot::Point` | Single plotted point |
| `Plot::Line` | Geodesic line segment between two points |
| `Plot::Vertices` | Vertex set rendering |
| `Plot::Multiline` | Connected line strip from a sequence of fragments |
| `Plot::Ring` | Circle rasterized as a plotted polyline |
| `Plot::PlanarPolygon` | Regular N-gon in the tangent plane |
| `Plot::SphericalPolygon` | Regular N-gon with geodesic (great-circle) edges |
| `Plot::DistortedRing` | Ring with per-azimuth radius perturbation via callback |
| `Plot::Spiral` | Fibonacci spiral on the sphere |
| `Plot::Star` | N-pointed star shape (alternating inner/outer radii) |
| `Plot::Flower` | N-petal flower shape |
| `Plot::Mesh` | Wireframe mesh rendering with edge deduplication |
| `Plot::ParticleSystem` | Particle trail rendering from `VectorTrail` history |
| `Plot::Bezier` | Single cubic Bézier curve on the sphere |
| `Plot::SplineChain` | Catmull-Rom spline chain through control points with configurable tension |

### 7.3 The Animation System (`animation.h`)

The `Timeline` class manages a list of running `IAnimation` objects. Each frame, `timeline.step(canvas)` advances all active animations. Finished animations are removed; repeating animations are rewound. All animation types inherit from `AnimationBase` and support method chaining via `.then()` for sequencing.

#### Animation Types

| Type | Description |
|---|---|
| `Rotation<W>` | Quaternion rotation of an `Orientation` around an axis, with optional repeat. Supports World and Local coordinate spaces. |
| `RandomWalk<W>` | Continuously perturbs an `Orientation` with smoothly changing random angular velocity driven by Perlin noise. Configurable via `Options` presets (Languid, Energetic). |
| `Motion<W, CAP>` | Moves an `Orientation` along a `Path` or `ProceduralPath` (the path is a constructor argument; `CAP` is the orientation sub-frame capacity, default 4) |
| `Sprite` | Calls a draw function over a duration with fade-in and fade-out envelopes |
| `PeriodicTimer` | Fires a callback at regular intervals (once or repeatedly) |
| `RandomTimer` | Fires a callback after a random delay within a min/max range |
| `Transition` | Smoothly interpolates a float variable from its current value to a target over a duration with easing |
| `Mutation` | Applies a custom scalar function to a float variable over time with easing |
| `Driver` | Continuously increments a float variable each frame (wraps at 0..1) |
| `Lerp` | Type-erased interpolation between any `T` that implements `lerp(start, target, t)`. The caller owns start, subject, and target data; Lerp holds pointers and a type-erased lerp function. |
| `ColorWipe` | Smoothly interpolates a `GenerativePalette` toward a target palette |
| `ParticleSystem<W>` | Physics simulation with emitters, attractors, friction, gravity. Particles have `VectorTrail` history for trail rendering. |
| `Ripple` | Animates a `RippleParams` to expand a Ricker wavelet across the sphere |
| `MobiusWarp` | Animates `MobiusParams` to apply and release a Möbius transformation |
| `MobiusWarpCircular` | Animates `MobiusParams` for a circular warp that stays warped throughout, suitable for repeating effects |
| `MobiusWarpEvolving` | Continuously modulates `MobiusParams` over multiple frequencies for a non-repeating, evolving warp |
| `MobiusFlow` | Animates `MobiusParams` for a continuous loxodromic flow |
| `Noise` | Animates `NoiseParams` over time for flowing distortion fields |
| `MeshMorph` | Morphs one `MeshState` into another by cloning both, building a nearest-vertex correspondence, and interpolating positions over a duration. The vertex-level primitive beneath `MeshCarousel`. |
| `MeshCarousel` | Double-buffered mesh transition system. Manages a pair of `MeshState` buffers and flips the front index eagerly so a freshly-scheduled `Animation::Sprite` captures the new shape. The crossfade emerges from **overlapping** sprites across consecutive transitions: each transition fades only its own incoming shape in (and back out), while the previous transition's sprite — still alive in its fade-out tail — keeps drawing the outgoing shape. No single call ever draws both meshes. Used by IslamicStars (sprite crossfade); MeshFeedback and HankinSolids reuse the buffered pair but drive vertex-level `MeshMorph` transitions over it instead. |

#### Orientation and Motion Blur

`Orientation<CAP>` stores a history of up to `CAP` quaternions (default 4) accumulated during one frame step. The template parameter is the history *capacity*, not the display width — effects use a small value like `Orientation<16>`, never `Orientation<288>`. The `World::Orient` filter iterates over this history to distribute motion blur: each point is plotted once per orientation step, with the `age` field increasing backward in time. This means fast-rotating effects naturally show streak-like motion blur with no extra code.

```cpp
timeline.add(0, Animation::Rotation<W>(orientation, Y_AXIS, 2 * PI_F, 600, ease_linear, true));
// orientation.orientations[] now grows by 1 per sub-step
// World::Orient distributes all steps → motion blur
```

`Orientation::upsample(count)` resamples the orientation history to a higher resolution via SLERP. This is used to rewrite the history when combining multiple animations for accurate parallel sub-frame path tracing — ensuring that concurrent rotations, motions, and walks all contribute to a single coherent set of intermediate orientations.

#### OrientationTrail

`OrientationTrail<OrientationType, CAPACITY>` maintains a circular buffer of past `Orientation` snapshots, allowing effects to recall where an object was over previous frames. Each snapshot is a full `Orientation` (with its own sub-frame history).

#### VectorTrail

`VectorTrail<CAPACITY>` maintains a circular buffer of past world-space `Vector` positions. Used by `ParticleSystem` to record per-particle trajectories for trail rendering.

#### `tween` and `deep_tween`

Two traversal helpers linearize multi-level orientation history into a single callback loop:

| Function | Input | Description |
|---|---|---|
| `tween(orientation, callback)` | `Orientation<CAP>` | Iterates over the sub-frame quaternion history of a single orientation, calling `callback(quaternion, t)` for each step with `t ∈ [0, 1]`. Used by `World::Orient` to distribute motion blur. |
| `deep_tween(trail, callback)` | Any `Tweenable` (`Orientation` or `OrientationTrail`) | Flattens a trail of orientations into a single continuous traversal, calling `callback(quaternion, t)` with a global `t` spanning all frames and sub-frames. Used by the orientation-trail effects (Comets, ChaoticStrings, RingSpin) for rendering trails with full sub-frame accuracy. |

#### Animations and Mutable State

Animations do not render directly — they mutate external state that the rendering pipeline reads. Each animation type targets a specific kind of mutable variable:

| Animation | Target State | What It Mutates |
|---|---|---|
| `Rotation`, `RandomWalk`, `Motion` | `Orientation<CAP>` | Quaternion orientation — pushes sub-frame steps into the orientation history, which `World::Orient` reads for motion blur |
| `Transition` | `float*` | Smoothly interpolates any float parameter (e.g. `speed`, `alpha`, `twist`) from current value to target with easing |
| `Mutation` | `float*` | Applies an arbitrary scalar function `f(t)` to a float over time (more general than `Transition`) |
| `Driver` | `float*` | Continuously increments a float each frame, wrapping at 0..1 — used for phase accumulators |
| `Lerp` | `T*` (type-erased) | Interpolates any type with a `lerp()` function — `MeshState`, params structs, etc. The caller owns start, subject, and target; Lerp holds pointers |
| `ColorWipe` | `GenerativePalette*` | Interpolates palette coefficients toward a target palette using `lerp_oklch_srgb` |
| `Ripple`, `MobiusWarp`, `Noise` | `TransformerParams` | Animate transformer parameters (expansion radius, warp strength, noise scale) which the transformer pool reads during `MeshOps::transform()` |
| `ParticleSystem` | `Vector[]` positions | Physics simulation updates particle positions; `VectorTrail` records history for trail rendering |

This separation means effects declare *what state exists* (orientations, floats, palettes) and *what animations drive that state* (rotations, transitions, drivers), but never manually interpolate or update values per-frame. The `Timeline` handles all timing, easing, sequencing, and cleanup:

```cpp
// Effect declares mutable state:
Orientation<16> orientation;   // CAP is the sub-frame capacity, not the display width
float twist = 0.0f;
GenerativePalette palette;

// Timeline drives state via animations:
timeline.add(0, Animation::Rotation<W>(orientation, Y_AXIS, TAU, 600, ease_linear, true));
timeline.add(0, Animation::Transition(twist, 2.5f, 1000, ease_in_out_cubic));
timeline.add(0, Animation::ColorWipe(palette, target_palette, 2000, ease_linear));

// Rendering reads state — no manual updates needed:
void draw_frame() {
    Canvas canvas(*this);
    timeline.step(canvas);  // all state updated automatically
    // orientation, twist, palette are now current-frame values
    filters.plot(canvas, v, palette.get(t), ...);
}
```

### 7.4 Geometry Transformers (`transformers.h`)

Transformers deform the sphere geometry before rendering. The `Transformer<ParamsT, AnimT, TransformFunc, CAPACITY>` class manages a pool of active transform instances, each with its own animated parameters:

```cpp
template <int CAPACITY>
using RippleTransformer = Transformer<RippleParams, Animation::Ripple,
                                      ripple_transform, CAPACITY>;
```

Available transformers:

| Transformer | Effect |
|---|---|
| `RippleTransformer` | Expands Ricker wavelets from a point, bending the sphere surface radially. Uses fast-reject dot-product heuristic — ~90-95% of vertices skip the slow `acosf` path. |
| `MobiusWarpTransformer` | Applies and releases a Möbius transformation |
| `MobiusWarpCircularTransformer` | Loops a Möbius warp continuously |
| `MobiusWarpGnomonicTransformer` | Möbius via gnomonic projection (preserves straight lines in hemisphere) |
| `NoiseTransformer` | Distorts surface positions with 3D simplex noise |
| `OrientTransformer` | Applies an `Orientation` quaternion rotation to all vertices |

Transformers integrate with the `MeshOps::transform()` pipeline and can be chained: `MeshOps::transform(input, output, arena, ripple_transformer, orient_transformer)`.

#### Standalone Utilities

`stereo_noise_warp()` (`transformers.h`) is a free function, not a `Transformer<>` specialization — it is called directly by effects rather than managed through the transformer pool. It takes an already-projected stereographic coordinate `z` (a `Complex`) plus its precomputed `r_sq` (|z|²) — the caller does the `stereo()` projection — and adds FastNoiseLite-driven displacement attenuated near the projection pole. Returns a `StereoWarpResult` containing the warped coordinate and displacement magnitude (used for hue shift by Liquid2D and Flyby).

### 7.5 Memory Architecture (`memory.h`, `memory.cpp`)

A single contiguous memory block (`GLOBAL_ARENA_SIZE = 330 KiB`) is partitioned into three arena allocators. This block is the same size on both Teensy and WASM targets. Individual effects can call `configure_arenas()` to repartition the block at runtime.

| Arena | Default Size | Purpose |
|---|---|---|
| `persistent_arena` | 298 KiB | Long-lived compiled mesh data, persists across frames |
| `scratch_arena_a` | 16 KB | Short-lived intermediate geometry (RAII scoped) |
| `scratch_arena_b` | 16 KB | Secondary scratch for ping-pong subdivision passes |

Effects that need more scratch memory can repartition at init time:

```cpp
// The three sizes must not exceed GLOBAL_ARENA_SIZE (330 KiB on device); an
// over-subscribed partition traps at init() via HS_CHECK rather than silently
// scaling down. Under-subscription is allowed (the surplus is just unused),
// but partitioning the full budget is the norm. Here scratch is doubled at the
// expense of persistent space:
configure_arenas(266 * 1024, 32 * 1024, 32 * 1024);  // 266 + 32 + 32 = 330 KiB
```

`ScratchScope` provides stack-like RAII lifetime:

```cpp
{
    ScratchScope scratch_a_guard(scratch_arena_a);  // save offset
    // ... allocate from scratch_arena_a ...
}                                        // restore offset — all allocations freed
```

All functions that require scratch memory take explicit `Arena&` parameters — there are no hidden arena references or implicit state:

```cpp
scratch_arena_a.reset();
scratch_arena_b.reset();
ScratchScope _a(scratch_arena_a);
ScratchScope _b(scratch_arena_b);
PolyMesh result = MeshOps::kis(mesh, scratch_arena_a, scratch_arena_b);
```

Conway operators take `(Arena& target, Arena& temp)`, generator functions take `(Arena& a, Arena& b)`, and `classify_faces_by_topology` takes `(Arena& scratch_a, Arena& scratch_b, Arena& persistent)`. This purely functional approach makes the memory layout during heavy geometric operations explicit at every call site.

#### Compaction with `Persist<T>`

`Persist<T>` is an RAII class that safely evacuates live data from the persistent arena, allowing it to be reset and defragmented, then automatically restores the data on destruction:

```cpp
{
    Persist<MeshState> p(live_mesh, scratch_arena_a, persistent_arena);
    persistent_arena.reset();
    // ... allocate fresh data into persistent_arena ...
}   // ~Persist: clones backup back into persistent_arena
```

#### Additional Data Structures

| Type | Description |
|---|---|
| `ArenaVector<T>` | Fixed-capacity, arena-backed vector (no dynamic growth). Copy-disabled, move-enabled. Debug builds detect use-after-free via arena generation tracking. |
| `ArenaSpan<T>` | Non-owning read-only view into an `ArenaVector` (explicit borrow) |

### 7.6 The Color System (`color.h`)

All internal color data is **16-bit linear light** (`uint16_t r, g, b` in range 0–65535). This avoids the precision loss and incorrect blending that occurs with gamma-encoded 8-bit values.

The conversion pipeline:
```
Input (sRGB 8-bit) → sRGB→linear LUT → Pixel16 (linear 16-bit) → blend ops
                                                                      ↓
FastLED output ← CRGB(gamma encode) ← linear→sRGB ← Pixel16
```

`Color4` wraps `Pixel` with a float alpha channel. The canvas sink composites with a single straight-alpha "over" operation — `blend_alpha(α)`, i.e. `dst = src * α + dst * (1-α)`, applied in 16-bit linear light (see `filter.h`). There is no selectable blend-mode tag.

`color.h` additionally provides standalone compositing helpers — `blend_over`, `blend_under`, `blend_add` (with an ARM `uqadd16` saturating-add path), `blend_max`, and `blend_mean` — as building blocks for additive/max/mean mixing. They are not wired into the canvas sink; an effect calls them directly when blending its own intermediate buffers.

#### Palette Types

| Type | Description |
|---|---|
| `ProceduralPalette` | Cosine palette: `a + b*cos(2π*(c*t + d))` per channel. Defined by 4 vec3 coefficients. |
| `Gradient` | Linear interpolation between a sorted list of (position, color) stops. |
| `GenerativePalette` | Procedurally generated palette from harmony rules (triadic, analogous, etc.) combined with brightness/saturation profiles. Supports snapshot/lerp for animated transitions. |
| `SolidColorPalette` | Constant color, adapts to the `Palette` interface. |

Twenty-one named `ProceduralPalette` instances are pre-defined: `darkRainbow`, `bloodStream`, `vintageSunset`, `richSunset`, `undersea`, `lateSunset`, `mangoPeel`, `iceMelt`, `lemonLime`, `algae`, `embers`, `fireGlow`, `darkPrimary`, `mauveFade`, `lavenderLake`, `desertRose`, `bruisedMoss`, `bruisedBanana`, `brightSunrise`, `fireAndIce`, and `peachPop`.

#### OKLCH Perceptual Color

All palette interpolation and procedural color generation is performed in the OKLCH perceptual color space. The pipeline:

```
Pixel (sRGB 16-bit) → linear RGB float → OKLab (L, a, b) → OKLCH (L, C, h)
                                                                  ↓
                                              shortest-arc hue interpolation
                                                                  ↓
                                    OKLCH → OKLab → linear RGB → Pixel
                                                       ↓ (only if out of gamut)
                                              reduce chroma, hold hue + L
```

| Function | Description |
|---|---|
| `linear_rgb_to_oklab()` | Convert linear RGB to the OKLab perceptual space |
| `oklab_to_oklch()` | Convert OKLab (rectangular) to OKLCH (polar: Lightness, Chroma, Hue) |
| `lerp_oklch()` | Interpolate two OKLCH values with shortest-arc hue (avoids the red→green→blue detour) |
| `lerp_oklch_srgb()` | Same as above but returns an sRGB `CPixel` (used by `GenerativePalette` transitions) |
| `gamut_clip_preserve_chroma()` | Maps an out-of-gamut OKLab color back into the sRGB cube by reducing chroma while holding hue and lightness (binary search on the chroma scale). The hue-preserving alternative to a per-channel RGB clip. Gated behind an in-gamut test (`oklab_to_linear_rgb_gamut`), so in-gamut colors — the vast majority — pay only the test and skip the search. |
| `hue_rotate()` | Perceptual hue rotation — rotates the (a,b) chroma plane in OKLab, preserving lightness and chroma. Forward nonlinearity uses `fast_cbrt` (hot per-pixel path); inverse is exact. Out-of-gamut results are chroma-reduced rather than per-channel clipped, which holds hue and stabilizes the feedback loop against saturated-color drift. Used by the feedback `hue_fade` transform and `Flyby`'s displacement-driven hue shift. |

#### Palette Modifiers

Modifiers compose around any palette source at compile time via
`StaticPalette<Source, Coords<...>, Colors<...>, Wrap>`. There are two axes: a
**coordinate** chain that remaps the lookup parameter `t` *before* the source is
sampled, and a **color** chain that reshapes the resulting sample *after*, with
the original coordinate in hand. Both chains are inlined by fold expression with
zero runtime overhead. `Wrap` (default `true`) wraps the final coordinate into
`[0,1)` before the lookup — leave it on for cycling modifiers that overflow the
range; set it `false` for bounded remaps that must reach the source endpoints.

Coordinate modifiers (`modify(float) -> float`):

| Modifier | Effect |
|---|---|
| `CycleModifier` | Shifts the lookup parameter by a continuously incrementing offset (palette scrolling) |
| `BreatheModifier` | Oscillates the lookup parameter with a sinusoidal "breathing" envelope |
| `RippleModifier` | Applies a wavelet distortion to the lookup parameter |
| `FoldModifier` | Folds the parameter space (mirror at edges) to create ping-pong patterns |
| `PinchModifier` | Non-linearly warps the lookup parameter toward a focal point |
| `QuantizeModifier` | Posterizes the palette into discrete bands |
| `ScaleModifier` | Scales and offsets the lookup parameter |
| `ReverseModifier` | Mirrors the lookup parameter (1.0 - t) |
| `MirrorModifier` | Maps [0,1] to [0,1,0] for a seamless symmetric loop |
| `InsetModifier` | Compresses the source domain into an inset window, clamping outside |

Color modifiers (`shade(Color4, float) -> Color4`):

| Modifier | Effect |
|---|---|
| `AlphaFalloffShade` | Scales alpha by a caller-supplied falloff curve over the coordinate |
| `EdgeFadeShade` | Fades the sample color to black near the edges (opaque vignette) |
| `EdgeAlphaShade` | Fades the sample alpha near the edges (transparent vignette) |

```cpp
// Compose a baked palette with a breathing coordinate modifier
StaticPalette<BakedPalette, Coords<BreatheModifier>> palette;

// A transparent vignette: inset the source, fade alpha at the edges
StaticPalette<ProceduralPalette, Coords<InsetModifier>,
              Colors<EdgeAlphaShade>, /*Wrap=*/false> vignette;
```

#### Additional Palette Types

| Type | Description |
|---|---|
| `MutatingPalette` | Extends `ProceduralPalette` with continuous coefficient mutation between two procedural palettes |
| `SolidColorPalette` | Returns a single fixed color for every coordinate |
| `PaletteFacade<SP>` | Exposes a compile-time `StaticPalette` composition through the polymorphic `Palette` API, for preset tables and baking |
| `BakedPalette` | Precomputes any palette source (a `Palette` or a `StaticPalette`) into a fast 16-bit LUT for O(1) lookup. Arena-allocated. |

### 7.7 The Mesh System (`mesh.h`, `conway.h`, `hankin.h`, `spatial.h`, `solids.h`)

The mesh system is split across several files:

- **`mesh.h`** — Core data structures (`PolyMesh`, `HalfEdgeMesh`) and fundamental `MeshOps` (compile, clone, classify)
- **`conway.h`** — Conway mesh operators and vertex transformations
- **`hankin.h`** — Hankin pattern compilation and dynamic update
- **`spatial.h`** — `MeshState` (flat-array renderer format) and `KDTree`
- **`solids.h`** — Platonic + Archimedean + Catalan + Islamic Star Pattern solid geometry data and registry

`PolyMesh` stores vertices and face connectivity via `ArenaVector` arrays. `MeshState` (in `spatial.h`) is the flat compiled format consumed by the renderer. `HalfEdgeMesh` provides a half-edge traversal structure built from either a `PolyMesh` or `MeshState`.

#### Core MeshOps (`mesh.h`)

| Operation | Description |
|---|---|
| `MeshOps::compile` | Convert a `PolyMesh` to the flat-array `MeshState` format used by the renderer |
| `MeshOps::clone` | Arena-safe deep copy |
| `MeshOps::classify_faces_by_topology` | Group faces by vertex count and neighbor topology for palette assignment |

#### Conway Operators (`conway.h`)

All Conway operators are templated on input mesh type and take `(const MeshT& mesh, Arena& target, Arena& temp)`. `MeshT` can be either `PolyMesh` or `MeshState`. **Primitive** operators produce their `PolyMesh` into `target` and use `temp` for intermediate computation. **Composed** operators (`gyro`, `meta`, `needle`, `zip`, `bevel`) reuse the same internal ping-pong as their two constituent ops, so they return their output in `temp` — the *opposite* arena from a primitive (see the load-bearing COMPOSITION POLARITY note in `conway.h`). Plan arena lifetimes accordingly when invoking a composed operator directly rather than through `SolidBuilder`:

| Operation | Description |
|---|---|
| `MeshOps::transform` | Apply a chain of vertex transformers to produce a new `MeshState` |
| `MeshOps::dual` | Dual mesh (faces ↔ vertices) |
| `MeshOps::kis` | Raise a pyramid on each face |
| `MeshOps::ambo` | Truncate vertices to edge midpoints |
| `MeshOps::truncate` | Cut corners off the polyhedron (configurable depth) |
| `MeshOps::expand` | Separate faces (ambo of ambo) |
| `MeshOps::chamfer` | Bevel edges (hexagonal expansion) |
| `MeshOps::snub` | Chiral semi-regular polyhedron with twist (Newell-method face normals) |
| `MeshOps::gyro` | Gyro operator (= dual ∘ snub) |
| `MeshOps::meta` | Meta operator = kis ∘ ambo |
| `MeshOps::needle` | Needle operator = kis ∘ dual |
| `MeshOps::zip` | Zip operator = dual ∘ kis |
| `MeshOps::bevel` | Bevel operator = truncate ∘ ambo |
| `MeshOps::relax` | Edge-length relaxation by spring forces on the unit sphere. |
| `MeshOps::normalize` | Project all vertices onto the unit sphere |

#### Hankin Pattern System (`hankin.h`)

| Operation | Description |
|---|---|
| `MeshOps::compile_hankin` | Pre-compute topological data for fast Hankin pattern updates |
| `MeshOps::update_hankin` | Update dynamic vertices based on angle parameter (no reallocation) |
| `MeshOps::hankin` | One-shot Hankin pattern generation (compile + update) |

`compile_hankin` produces a `CompiledHankin` struct containing base vertices, static midpoints, and dynamic instructions. `update_hankin` evaluates the dynamic vertices by sweeping the Hankin angle, producing the star polygon line intersections for each face without reallocating memory.

#### Solids Library (`solids.h`)

`solids.h` provides constexpr vertex/face data for all Platonic solids plus procedural generators for Archimedean, Catalan, and Islamic Star Pattern families. The solids are organized into three registries, accessed by name via `Solids::get_by_name(arena, a, b, name)` (the firmware entry point) or by registry index via `Solids::get(arena, a, b, index)` — the latter is compiled only for the WASM build (`#ifdef EMSCRIPTEN`), where the geometry tools drive solids by numeric index:

| Registry | Count | Description |
|---|---|---|
| `simple_registry` | 16 entries | 5 Platonic (tetrahedron through icosahedron) + 11 Archimedean solids |
| `catalan_registry` | 13 entries | Duals of the Archimedean solids (triakisTetrahedron, rhombicDodecahedron, pentakisDodecahedron, etc.) |
| `islamic_registry` | 23 entries | Complex multi-operator recipes producing Islamic star patterns from base solids |

Total: **52 registered solids** (`Solids::NUM_ENTRIES`).

`Collections` namespace provides typed spans for iterating subsets: `get_platonic_solids()`, `get_archimedean_solids()`, `get_simple_solids()`, `get_catalan_solids()`, `get_islamic_solids()`.

`SolidBuilder` provides a fluent interface for chaining Conway operators with automatic arena swapping:

```cpp
return SolidBuilder(to_polymesh<Icosahedron>(a), a, b)
    .truncate()
    .dual()
    .build();
```

Islamic Star Pattern recipes chain multiple operators with Hankin pattern generation:

```cpp
SolidBuilder(dodecahedron(a, b), a, b)
    .hankin(54.0f * D2R).ambo().hankin(72.0f * D2R).build();
```

### 7.8 Generators (`generators.h`)

`generators.h` provides a single universal generation wrapper that manages arena lifecycle for all procedural geometry creation:

```cpp
template <typename GenerateFn, typename... Args>
auto generate(Arena &target, GenerateFn &&fn, Args &&...args);
```

It resets and scopes both scratch arenas, then invokes `fn(target, scratch_a, scratch_b, args...)`. Direct registry lookups and effect geometry creation go through this wrapper for a deterministic arena lifecycle:

```cpp
auto mesh = generate(persistent_arena, Solids::get_by_name, std::string_view("icosahedron"));
```

One deliberate exception: `SolidBuilder`'s fluent Conway chain (`solids.h`) owns its own two-arena ping-pong, swapping the scratch arenas between operators, so it manages arena lifecycle directly rather than through `generate()`.

### 7.9 The Preset System (`presets.h`)

`Presets<Params, Size>` is a generic template for managing parameter presets. It stores a fixed-size array of `PresetEntry<Params>` (each containing only a `Params` struct — no name field) and provides navigation and interpolation support:

```cpp
Presets<MeshFeedbackParams, 4> presets = {{
    {{{0.95f, 1.2f, ...}}},
    {{{0.88f, 0.5f, ...}}},
    ...
}};
presets.next();  // advance to next preset
presets.apply(current_params);  // copy current preset into live params
```

### 7.10 Hardware Drivers (`dma_led.h`, `pov_single.h`, `pov_segmented.h`)

Three hardware drivers form a layered stack.  `dma_led.h` handles the SPI wire protocol; `pov_single.h` and `pov_segmented.h` sit above it and manage the POV column sweep, differing only in how many Teensys share the work.

#### DMA LED Controller (`dma_led.h`)

Non-blocking DMA-based LED output for HD107S (APA102-compatible) LEDs on Teensy 4.x.  Enabled by `#define USE_DMA_LEDS` in the target sketch (e.g. `targets/Phantasm/Phantasm.ino`) before it includes the driver; `led.h` stays neutral (the define is commented out there) and the default FastLED/WS2801 path remains as fallback.

| Class | Role |
|---|---|
| `HD107SFrame<N>` | Pre-formatted DMA buffer for the HD107S protocol. `packPixel()` writes `Pixel16` values directly into the frame buffer with inline color correction (color correction → temperature → brightness), bypassing the CRGB intermediate. The buffer is 32-byte-aligned (`__attribute__((aligned(32)))`) and cleaned with `arm_dcache_flush()` (clean, no invalidate — the buffer is TX-only) for cache coherency. |
| `TeensySPIDMA` | Low-level DMA+SPI driver wired to LPSPI4. Configures a `DMAChannel` with completion interrupt for fully async byte-stream transmission. |
| `DMALEDController<N>` | Double-buffered high-level controller. The ISR packs pixels into `backFrame()`, then `submitFrame()` flushes it and triggers async DMA, returning immediately. If the previous transfer is still in flight, `submitFrame()` **drops** the new frame (bumping `getOverrunCount()`) rather than spinning — the in-flight DMA keeps showing the previous column; a transfer that never completes is surfaced as a wedged-channel fault. |

The 16-bit linear pipeline reaches from the canvas all the way to the SPI wire with no 8-bit intermediate:

```cpp
// ISR path (per column): fetch the display buffer once, index it directly
const Pixel* buf = effect_->display_buffer();              // 16-bit linear pixels
// Physical LED index comes from the single-source-of-truth map (pov_single_map.h),
// which applies the top-arm reversal / bottom-arm offset — never the raw row index.
frame.packPixel(pov::strip_top_led(y, S), buf[y * width + x]); // Pixel16 → HD107S frame
ledController_.submitFrame();                               // non-blocking DMA, drops on overrun
```

#### Single-Teensy POV Driver (`pov_single.h`)

`POVDisplay<S, RPM>` drives the Holosphere — one Teensy owns the entire LED strip.  An `IntervalTimer` ISR fires at `1,000,000 / (RPM/60) / width` µs intervals to advance one column:

```
Main Loop                              ISR (IntervalTimer)
──────────                             ───────────────────
effect->draw_frame()                   show_col() fires every N µs
  Canvas canvas(*this)                   for y in 0..S/2:
    render to bufs_[cur_]                  packPixel(strip_top_led(y,S),    get_pixel(x, y))                      // top arm
  ~Canvas → queue_frame()                  packPixel(strip_bottom_led(y,S), get_pixel(strip_opposite_col(x,W), y)) // bottom arm
                                         submitFrame() → async DMA
                                         x = (x+1) % width
                                         if x==0 || x==width/2: advance_display()
```

The top arm's physical LED ordering is reversed (LED 0 at the tip, descending in Y), and the bottom arm shows the opposite half of the image (x offset by W/2).

| Parameter | Value (Holosphere) |
|---|---|
| S (total pixels) | 40 |
| RPM | 480 |
| Column interval | ~1302 µs (= 125 ms / 96 columns) |
| ISR duration | ~20 µs |

#### Multi-Teensy Segmented POV Driver (`pov_segmented.h`)

`POVSegmented<S, N, RPM>` drives Phantasm — N Teensys (typically 4) each control a contiguous Y-segment of the LED strip on a single arm.  Two Teensys sit on each arm: one at the N pole (top), one at the S pole (bottom).

**Physical strip layout (N=4, S=288):**

```
Arm A                               Arm B (x offset by W/2)
┌──────────────────────────┐        ┌──────────────────────────┐
│ Seg 0 (top)              │        │ Seg 2 (top)              │
│ LED 0 at N pole (y=0)    │        │ LED 0 at N pole (y=0)    │
│ → LED 71 at junction     │        │ → LED 71 at junction     │
├────────── junction ──────┤        ├────────── junction ──────┤
│ Seg 1 (bottom, reversed) │        │ Seg 3 (bottom, reversed) │
│ LED 0 at S pole (y=143)  │        │ LED 0 at S pole (y=143)  │
│ → LED 71 at junction     │        │ → LED 71 at junction     │
└──────────────────────────┘        └──────────────────────────┘
```

**Hardware ID detection**: Each Teensy reads a 2-bit ID from GPIO pins 21–22 (active-low with pull-ups).  All-floating = ID 0 (sync master).  The ID determines which arm and which half this board owns.

**Branchless ISR**: All per-segment decisions are resolved at boot time into three precomputed values:

| Value | Description |
|---|---|
| `y_base_` | Starting Y index for LED 0 (0 for top segments, ROWS-1 for bottom) |
| `y_step_` | +1 (top, forward) or -1 (bottom, reversed) |
| `arm_b_` | Whether this segment is on arm B (x offset by W/2) |

The ISR loop has no branches:

```cpp
const Pixel* buf = effect_->display_buffer();   // fast path: no per-pixel virtual dispatch
int y = y_base_;
for (int i = 0; i < PPS; ++i, y += y_step_) {
    frame.packPixel(i, buf[y * width + x_col]);
}
```

**Effect transparency**: Effects render the full 288×144 canvas — segmentation is handled entirely in the ISR.  No changes to any effect code are needed.  All 4 boards share the same deterministic random seed (`Pcg32(1337)` in `platform.h`), so identical effect sequences produce identical canvases.

| Parameter | Value (Phantasm) |
|---|---|
| S (total pixels) | 288 |
| N (segments) | 4 |
| PPS (pixels per segment) | 72 |
| RPM | 480 (8 rev/s, ~125 ms/rev) |
| Frame rate | 16 FPS (2 frames/rev — one per side; each side draws W/2 = 144 cols per 62.5 ms frame) |
| Column frequency | 2304 Hz |
| Column interval | ~434 µs (= 125 ms / 288 = 62.5 ms / 144) |
| ISR duration (72px pack + DMA trigger) | ~96 µs worst case |

#### Frame Sync Protocol: 1-Wire Signal Datasheet

Phantasm's four boards stay coherent over **one wire**.  Segment 0 (the **master**) is the conductor; segments 1–3 (**downstream**) listen.  Each board generates its own columns from a local **flywheel timebase** and snaps that timebase to count-coded pulse bursts the master broadcasts on the wire.  Full design: `docs/phantasm_frame_sync_spec.md`; host-tested protocol core: `hardware/pov_sync.h`.

The flywheel derives the column index from the free-running CPU cycle counter, never from counting timer interrupts:

```
x = ( x_boundary + (now − epoch) · (W/2) / cycles_per_half_rev )  mod W
                                                    └─ 64-bit intermediate
```

`epoch` is folded forward by exactly one half-revolution at every boundary crossing, so the 32-bit cycle counter's ~7.16 s wrap is structurally unobservable.  An interrupt-masked window (e.g. `FastLED.show()`) cannot drop columns — the ISR that runs after the mask reads the clock and resumes at the *time-correct* column.

**Pin / signal description.**

| Signal | Master (seg 0) | Downstream (seg 1–3) | Electrical | Direction |
|---|---|---|---|---|
| `SYNC` | pin 3 (GPIO out) | pin 4 (ext. interrupt in) | 3.3 V CMOS, active-high pulses, idle LOW | master → all |
| `ID[1:0]` | pins 21–22 | pins 21–22 | active-low, internal pull-ups | strap (board identity) |

`ID[1:0]` straps select the board: all-floating = `00` = master; the other three codes select arm/half.  The former column-clock wire is **deleted** — `SYNC` is the only inter-board connection.  It is assumed physically reliable (a hard, soldered line); a severed wire is out of scope (boards free-run and precess apart at crystal rate, a slow smear, never an instant break).

**Signal levels & symbol waveforms.** The wire idles LOW.  A **symbol** is a burst of short active-high pulses at a fixed pitch; **the meaning is the count of rising edges — pulse width carries no information.**  Each pulse is HIGH for one ISR body (pin set HIGH at ISR entry, LOW at exit; tens of µs) and the rising edge is the only timed event.  Pulses are drawn narrow, to scale against the ~868 µs pitch:

```
 HALF — 1 pulse — marks boundary x = W/2 (144)
            ┌┐
 ───────────┘└──────────────────────────────────────────────────  idle LOW
            ▲
            └ boundary instant (x = W/2)

 ZERO — 3 pulses — marks boundary x = 0
            ┌┐      ┌┐      ┌┐
 ───────────┘└──────┘└──────┘└───────────────────────────────────
            ▲   └ 2-col pitch ┘
            └ boundary instant (x = 0)

 ZERO+EPOCH — 5 pulses — marks x = 0 AND advances the playlist
            ┌┐      ┌┐      ┌┐      ┌┐      ┌┐
 ───────────┘└──────┘└──────┘└──────┘└──────┘└───────────────────
            ▲
            └ boundary instant (x = 0)
```

A burst terminates when the wire stays quiet past the **gap timeout** (4 columns).  The consumer counts rising edges and classifies:

| Symbol | Edges | Marks | Carries | Rate |
|---|---|---|---|---|
| `HALF` | **1** | boundary `x = W/2` | half-rev phase + flip | 1 / rev |
| `ZERO` | **3** | boundary `x = 0` | half-rev phase + flip | 1 / rev |
| `ZERO+EPOCH` | **5** | boundary `x = 0` | phase + flip + **playlist advance** | 1 / effect (×R repeats) |
| `BEACON` | 5 base-8 digits @ `x ≈ W/4` | — (data channel) | absolute effect index + rev count, checksummed | rev ≡ 1 (mod 16) + first revs of an effect |
| *invalid* | any **even** count, or > 5 | — | discarded whole: no snap, no flip, no advance | — |

**Why count, not width:** on the i.MX RT each pin has a single latched interrupt flag, so an IRQ-mask window *delays* an edge's ISR but cannot lose the edge unless two edges fall inside one mask window.  With pulse pitch chosen **greater than the worst-case mask window M**, the edge *count* is exact even when `FastLED.show()` masks IRQs mid-symbol (on Phantasm's DMA LED path, M ≈ 0).  The alphabet is **odd-only, distance 2** — a single lost or spurious edge lands on an even (invalid) count and is discarded.  A glitch degrades to a *missed* symbol (covered by the local boundary crossing), **never** a *misclassified* one: *fail to "missed," never to "wrong."*

**AC timing characteristics.** At 480 RPM / 600 MHz / W = 288 (1 column = 434.03 µs = 260,417 cycles):

| Parameter | Symbol | Columns | Time | Cycles | Rule |
|---|---|---|---|---|---|
| Column period | T0 | 1 | 434.0 µs | 260,417 | `cycles_per_half_rev / (W/2)` |
| Boundary pulse pitch | t_PB | 2 | 868.1 µs | 520,833 | **pitch > M** ⇒ no edge lost to the latch |
| Beacon digit pitch | t_PD | 1 | 434.0 µs | 260,417 | checksum tolerates tighter pitch |
| Burst gap timeout | t_GAP | 4 | 1.736 ms | 1,041,667 | **> pitch + M** ⇒ a mask can't split one burst |
| Glitch filter (min edge spacing) | t_GF | — | 100 µs | 60,000 | edges closer than this are EMI — rejected |
| Master late-censor budget | t_LATE | ½ | 217 µs | 130,208 | first pulse later than this ⇒ skip whole symbol |
| ACQUIRE quiet-before guard | t_QB | 16 | 6.94 ms | 4,166,667 | a hard snap requires this much prior silence |
| Beacon interdigit timeout | t_BID | 24 | 10.4 ms | 6,250,000 | stale partial beacon frame dropped after this |
| Half-revolution | — | 144 | 62.5 ms | 37,500,000 | one image / one flip interval |
| Revolution | — | 288 | 125 ms | 75,000,000 | two flips, two boundary symbols |

All bursts are ≪ the 62.5 ms half-rev, so consecutive symbols never overlap.

**One-revolution signal map.** Where each symbol lands across a single 125 ms revolution (beacon only on scheduled revolutions):

```
 column x →    0           72(W/4)        144(W/2)        216           288 ≡ 0
               │             │              │              │              │
 SYNC wire   ██ZERO     ░░░BEACON░░░      ██HALF                       ██ZERO
             (3 edges)  (5 digits, data)  (1 edge)                     (3 edges)
               │←─────────── half-rev = 62.5 ms ──────────→│
 display     flip A                       flip B                       flip A
 layer 1     snap φ                       snap φ                       snap φ
               │←──────────────────── revolution = 125 ms ────────────────────→│
```

Boundary symbols (`ZERO`/`HALF`) serve **two** layers at once: they snap the flywheel's column phase (Layer 1) *and* act as the exactly-once flip backstop (Layer 2).  The beacon rides the otherwise-quiet stretch at `x ≈ W/4`, separating the timing channel and the data channel **in time** on the same wire.

**The three disciplined layers.** Every layer reads the same flywheel timebase, so one snap corrects all three coherently; each also has an absolute reference on the wire that pulls it back if it drifts:

* **Layer 1 — Column phase.** Boundary symbols snap each flywheel twice per revolution; worst-case inter-snap crystal drift is **~0.006 column** at 40 ppm — far below a visible seam, which is the quantitative justification for deleting the column-clock wire.  In **LOCKED** a symbol is accepted only if its implied correction is **≤ G = 4 columns** and its boundary identity matches the flywheel's prediction (the plausibility gate).
* **Layer 2 — Buffer flip.** The local boundary crossing flips the display buffer; the symbol is a deduplicated backstop.  `try_flip`, keyed on boundary identity (boundaries strictly alternate `ZERO, HALF, …`), makes the flip **exactly-once** even when both the crossing and the symbol fire.  Losing both paths in one half-rev is the only glitch, and it self-heals the next half-rev.
* **Layer 3 — Content.** The playlist is **epoch-counted**, not `millis()`-gated.  The master emits the `EPOCH` mark (plus R = 3 redundancy repeats) when an effect's 960 revolutions elapse; every board counts down to the same **absolute** commit boundary regardless of which copy it heard, constructs the next roster entry during the final K = 2-revolution **construction window** (display black on all boards simultaneously), and all swap to its frame 0 at the same boundary.  The beacon broadcasts the absolute effect index so a board that missed every epoch repeat corrects within ~2 s, and a rebooted board rejoins at the correct effect — **fail-dark, never fail-wrong** (a board with no established identity shows black rather than a guessed effect).

**Index beacon frame format.** The beacon is a **data** symbol (integrity by *rejection*, not by exactness).  Five base-8 digits at 1-column pitch, each digit a burst of `digit + 1` pulses, digits separated by 5 quiet columns (one past the gap timeout, so the decoder reliably terminates each digit):

```
 Frame = [ idx_hi  idx_lo  rev_hi  rev_lo  checksum ]   (5 digits, base-8)
           └── effect index 0–63 ──┘ └ rev mod 64 ┘  └ Σ(i+1)·dᵢ mod 8

 digit Dk transmitted as (Dk+1) pulses @ 1-col pitch, then a 5-col quiet gap:

         D0          D1               D2          …        D4
        ┌┐          ┌┐┌┐┌┐           ┌┐┌┐                 ┌┐┌┐┌┐
 ───────┘└──/ /─────┘└┘└┘└──/ /──────┘└┘└──/ /───────────┘└┘└┘└──────────
        │←Dk+1 pulses→│   │←5-col quiet (terminates digit)→│
        │←──────────── frame ≈ 26 ms worst case (≪ half-rev) ───────────→│
```

Any checksum mismatch, wrong digit count, out-of-range digit, or stale partial frame **drops the whole frame** — the next beacon is ≤ 2 s away.  Schedule: revolution 1 of every 16 (`rev ≡ 1 mod 16` — never rev 0, so a just-powered board meets clean isolated boundary symbols first), plus the first revs of a fresh effect; silent during a pending commit.

**Receiver state machine.** Each downstream board is in one of two states.  The master is born `LOCKED` with identity (effect 0, rev 0) — it *is* the reference and never snaps:

```
                  first accepted snap
   ┌──────────────┐ ──────────────────▶ ┌──────────────┐
   │   ACQUIRE    │                      │    LOCKED    │
   │  (display    │                      │ (disciplined,│
   │   black)     │ ◀────────────────── │  rendering)  │
   └──────────────┘  R = 4 consecutive   └──────────────┘
                     gate rejections
                     (~2 revolutions)

 ACQUIRE : accept any *valid* symbol unconditionally (hard snap), but only
           on a burst preceded by ≥ t_QB (16 col) of wire silence — so a
           beacon digit train can't capture a just-rebooted board. Renders
           black until it has BOTH phase (a snap) AND identity (epoch/beacon).
 LOCKED  : accept a valid symbol only if implied correction ≤ G (4 col) AND
           boundary identity matches the prediction. Else reject (telemetry,
           no snap, no flip). After R rejections the board concludes its OWN
           timebase is at fault and falls back to ACQUIRE (the escape hatch
           that stops a genuinely-lost board from rejecting good symbols
           forever).
```

**Epoch commit sequence.** `EPOCH` at ZERO boundary **B** schedules an absolute commit at **B + R + K** (R = 3 repeats, K = 2 construction revolutions).  A board hearing any repeat infers its position in the train from its own revolution count and lands on the *same* boundary:

```
 ZERO boundary:   B        B+1      B+2      B+3      B+4      B+5
 master emits:   ●EPOCH    ○rpt     ○rpt     ○rpt      —        —
                 (5 edges) (5)      (5)      (5)
 commit_in_revs:   5        4        3        2        1        0
                 │←──── announce: keep playing OLD effect ────│
                                            │←── construct ──→│ swap → NEW
                                            ░░░ display BLACK ░░░  frame 0
 all boards:     ─────── outgoing effect ──────────░build/dark░── new effect
```

The dark window is identical (K revolutions) on every board because construction can't begin before B+R — only then is the window's start common knowledge regardless of which copy each board heard.  An effect that can't construct inside K revolutions trips `HS_CHECK` (fail-fast).  All boards reseed `hs::random()` (1337) per effect build, so the new instance is bit-identical no matter what each board rendered — or whether it even existed — before the epoch.

**Concurrency & failure modes.** Two ISRs per board, **single-writer** by construction.  The sync-wire RISING ISR is a pure *publisher* — glitch filter, edge count, first-edge timestamp into a small mailbox, nothing else.  The flywheel ISR (waking ~8× per column) is the sole *consumer/owner* of all sync state: it claims terminated bursts, classifies, gates, snaps, flips, and runs epoch scheduling.  The hot path is ~7-of-8 wakes doing one cycle-counter read and a 64-bit position compute (≈1 % CPU at 600 MHz); only a column change packs pixels and submits DMA.

| Event | Layer 1 (column) | Layer 2 (flip) | Layer 3 (content) |
|---|---|---|---|
| Masked-IRQ window (`FastLED.show()`) | resumes at time-correct column | unaffected | unaffected |
| 1 dropped boundary symbol | coasts ≤ 1 rev (~0.01 col); re-snaps next | local crossing still flips | unaffected |
| 1 spurious / EMI edge | even count discarded, or gate rejects | identity dedup no-ops it | epoch refractory + gate guard it |
| Late-emitted symbol | master self-censors; residual gate-rejected | crossing flips on time regardless | unaffected |
| 1 board renders slow (drops a frame) | — | shows prior frame for 1 period | stateless: heals next frame/beacon; stateful: heals next epoch |
| 1 dropped epoch symbol | — | — | R repeats; missed-all-R corrected by next beacon (~2 s) |
| Board reboots mid-show | re-acquires phase from next valid symbol | resumes flipping once LOCKED | rejoins correct effect via beacon, ≤ ~2 s; dark until then |
| Sync wire severed (out of scope) | free-runs on own crystal; precesses ≥ 1 col in ~10–20 s | keeps flipping locally | holds last effect; slow drift, never an instant break |

The flywheel ISR maintains telemetry counters (symbols accepted / gate-rejected / discarded, beacons ok / rejected, index corrections, epochs refractory-ignored, lock transitions, flips, emissions censored / aborted, longest coast) that the foreground reports behind `hs::debug` at ≤ 1 Hz — so any degradation the protocol absorbs silently is still visible at a glance.

---

## 8. The Effect System

Every visual effect inherits from `Effect`:

```cpp
template <int W, int H>
class MyEffect : public Effect {
public:
    MyEffect() : Effect(W, H), filters(...) {}

    void init() override {
        registerParam("Speed", &speed, 0.0f, 10.0f);
        persist_pixels = false;   // clear buffer each frame (this is the default)
    }

    bool strobe_columns() const override { return false; }

    void draw_frame() override {
        Canvas canvas(*this);       // acquire write buffer
        timeline.step(canvas);      // advance all animations
        // ... custom rendering ...
    }

private:
    Pipeline<W, H, ...> filters;
    Orientation<16> orientation;   // CAP is the sub-frame capacity, not the display width
    Timeline timeline;
    float speed = 1.0f;
};

REGISTER_EFFECT(MyEffect)
```

### Self-Registering Factory (`effect_registry.h`)

Effects register themselves into a global registry using the `REGISTER_EFFECT(ClassName)` macro placed at the bottom of each effect header. This uses a static initializer pattern — each effect creates a small registrar struct whose static member calls `EffectRegistry::add()` during program initialization, eliminating the need for a hand-maintained factory array. The registry stores resolution-specific fill functions for each supported `<W,H>` pair (96×20 and 288×144).

### Parameter Registration

Effects expose live-adjustable parameters via `registerParam()`. These are reflected into the WASM bridge and auto-generate GUI controls in the simulator:

```cpp
registerParam("Twist",   &params.twist, -5.0f, 5.0f);   // float slider (min, max)
registerParam("Enabled", &params.enabled);              // boolean toggle (bool* overload takes no range)
```

The parameter list (`ParamList` — a fixed `std::array<ParamDef, 32>`) is accessible via `getParameters()`, and `updateParameter(name, float)` sets values at runtime. Parameters support both `float*` and `bool*` targets via `std::variant`, with automatic bool threshold at 0.5. The animation system can also write to these parameters, allowing effects to animate their own exposed controls.

### The `persist_pixels` Flag

When `persist_pixels = true`, `Canvas` copies the previous frame's buffer into the new write buffer before rendering. This enables trail/decay effects without explicit trail storage — each frame partially overwrites the last. When `false` (the default), the buffer is zeroed each frame.

---

## 9. Effects Reference

All screenshots below were captured from the [live WebAssembly simulator](https://woundedlion.github.io/daydream/) at the Phantasm 288×144 resolution.

### Core Effects (Modern Engine)

<table border="0"><tr>
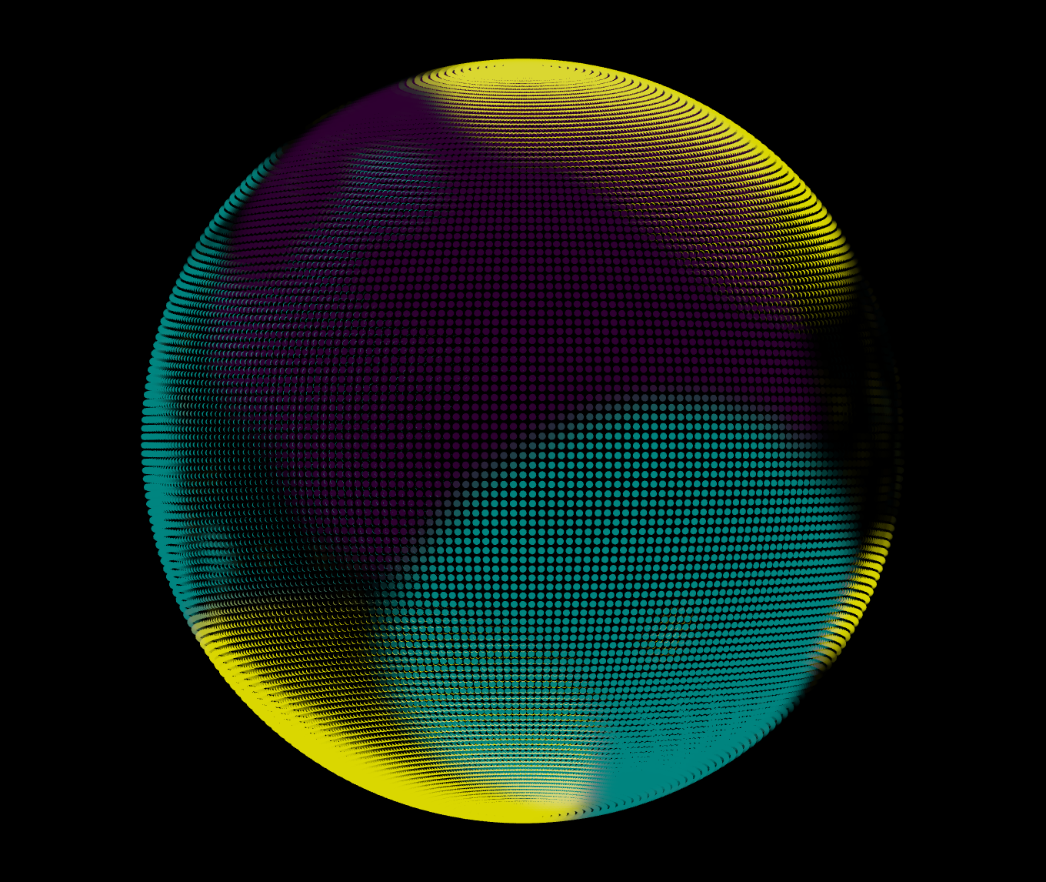
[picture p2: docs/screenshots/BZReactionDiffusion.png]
BZReactionDiffusion
<td width="300"></td>
<td valign="top">

#### BZReactionDiffusion

Simulates the Belousov-Zhabotinsky reaction — a 3-species cyclic competition (A beats B, B beats C, C beats A) producing rotating spiral waves. The simulation runs on a spherical k-nearest-neighbor graph (`ReactionGraph`: 7680 nodes, 6 neighbors each, precomputed Fibonacci lattice) with configurable diffusion rate and time step. Spiral waves are seeded periodically and evolve continuously.

**Parameters**: Compete (cyclic-competition/predation coefficient), Diff (diffusion rate), Speed (time step)

</td></tr></table>

<table border="0"><tr>
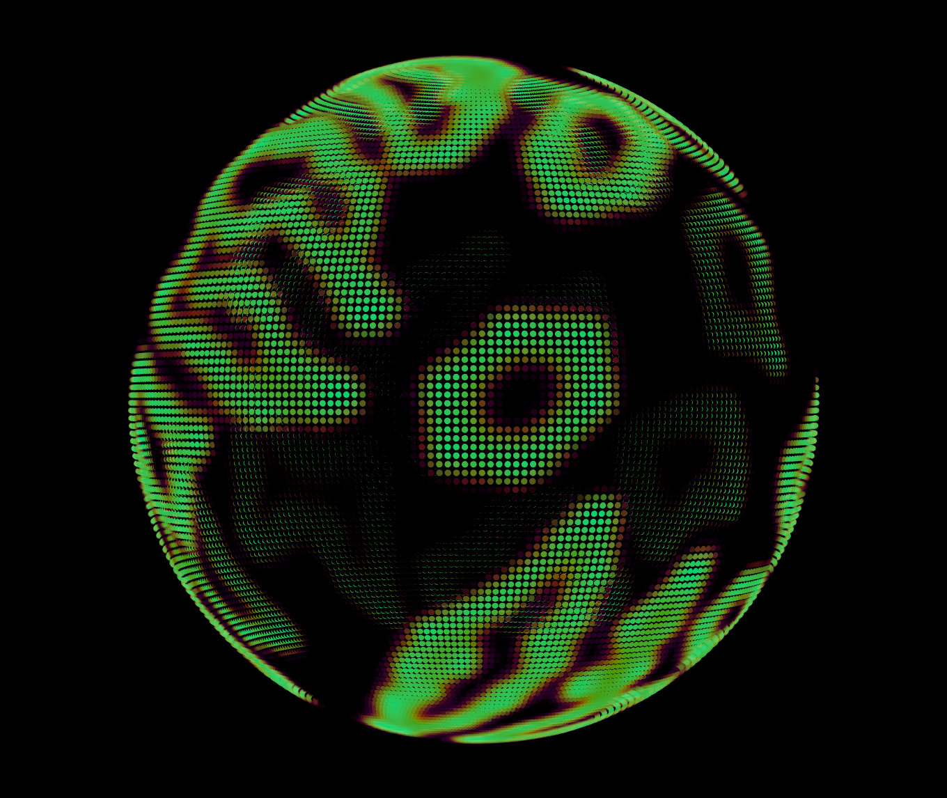
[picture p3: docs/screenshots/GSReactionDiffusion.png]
GSReactionDiffusion
<td width="300"></td>
<td valign="top">

#### GSReactionDiffusion

Gray-Scott reaction-diffusion system (U + 2V → 3V, V → P) on a spherical mesh. Produces spots, stripes, and labyrinthine patterns depending on feed/kill rates.

</td></tr></table>

<table border="0"><tr>
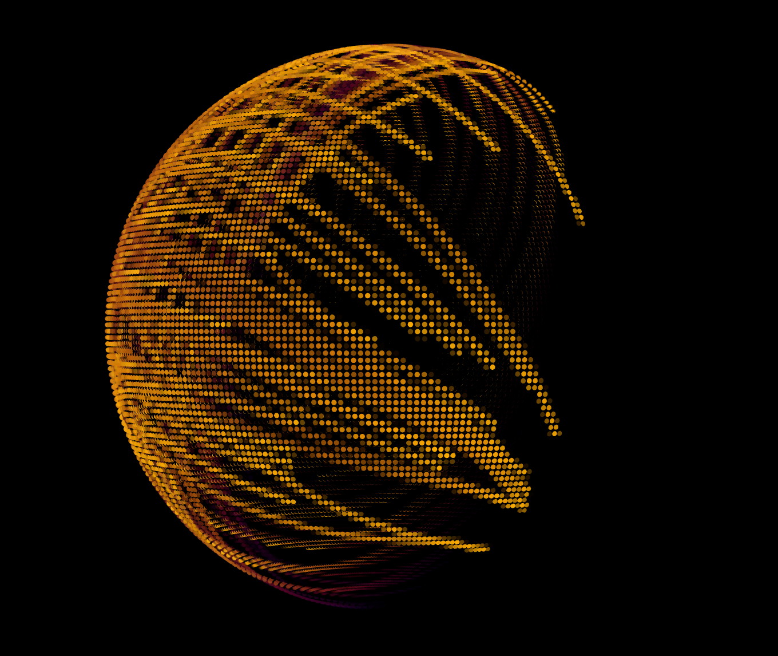
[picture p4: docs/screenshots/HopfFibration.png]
HopfFibration
<td width="300"></td>
<td valign="top">

#### HopfFibration

Visualizes the Hopf fibration — a map from S³ to S². Points on S² (the base space) are lifted to fibers on S³ via the quaternion parameterization `q = [cos(η)cos(φ+β), cos(η)sin(φ+β), sin(η)cos(β), sin(η)sin(β)]`, then stereographically projected to R³ and plotted on the sphere. A 4D tumble (R_xw × R_yz rotation) continuously rotates the fibration.

**Parameters**: Flow Spd, Tumble Spd, Folding, Twist, Alpha

</td></tr></table>

<table border="0"><tr>
<td width="300"><a href="https://woundedlion.github.io/daydream/?effect=IslamicStars" target="_blank">IslamicStars</a></td>
<td valign="top">

#### IslamicStars

Procedurally generates Islamic geometric patterns using Hankin's method (pentagon-based subdivision of the Archimedean solids). Each face of a rotating solid is decorated with its characteristic star polygon, colored by face topology (triangles, pentagons, hexagons, etc.). Ripple waves periodically distort the geometry.

**Parameters**: Duration, Fade, Burst, Ripp Amp, Ripp Width, Ripp Decay, Ripp Dur, Debug BB

</td></tr></table>

<table border="0"><tr>
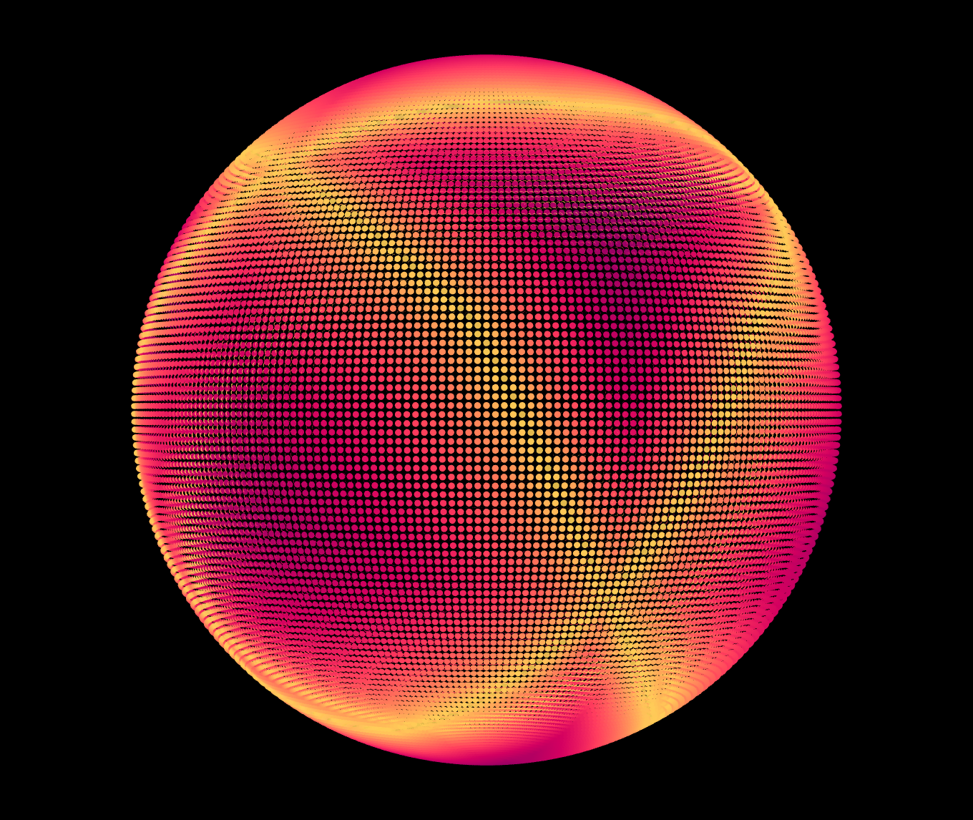
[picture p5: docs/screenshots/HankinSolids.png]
HankinSolids
<td width="300"></td>
<td valign="top">

#### HankinSolids

Similar to IslamicStars but sequences through the full Archimedean solid library with animated palette transitions.

</td></tr></table>

<table border="0"><tr>
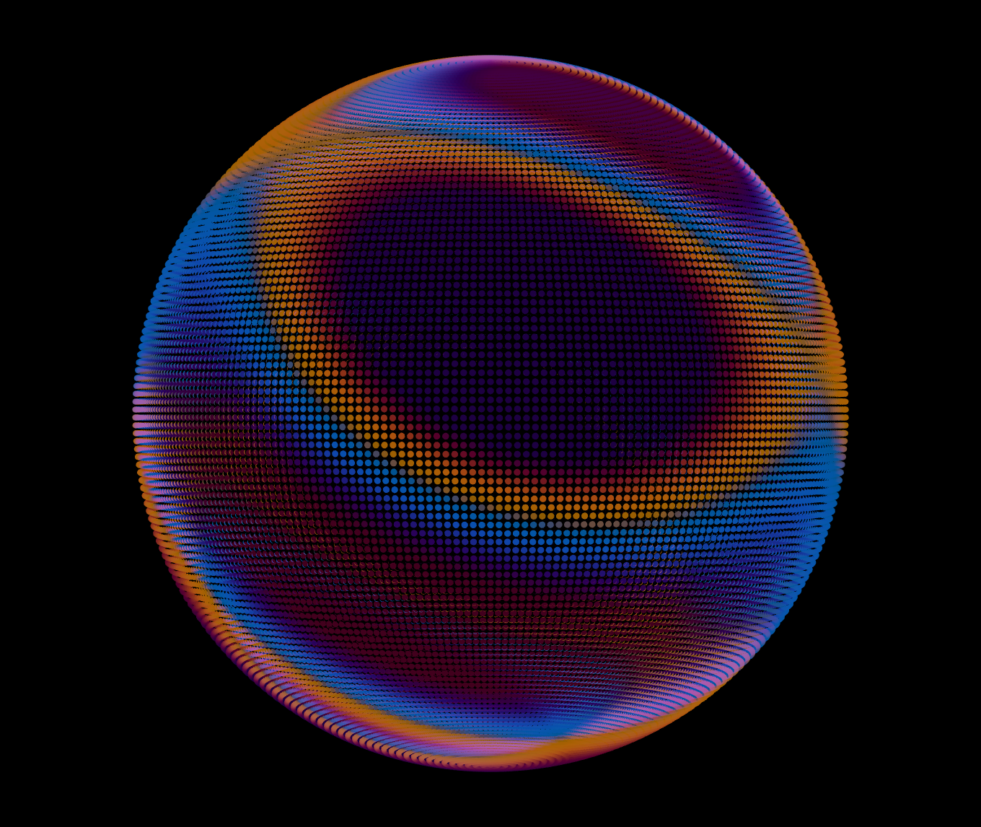
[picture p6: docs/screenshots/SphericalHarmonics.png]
SphericalHarmonics
<td width="300"></td>
<td valign="top">

#### SphericalHarmonics

Visualizes the real spherical harmonics Yˡₘ(θ, φ) as a colored scalar field over the sphere: the harmonic value drives a perceptual positive/negative palette split with ambient-occlusion shading. Continuously morphs between (l, m) modes.

</td></tr></table>

<table border="0"><tr>
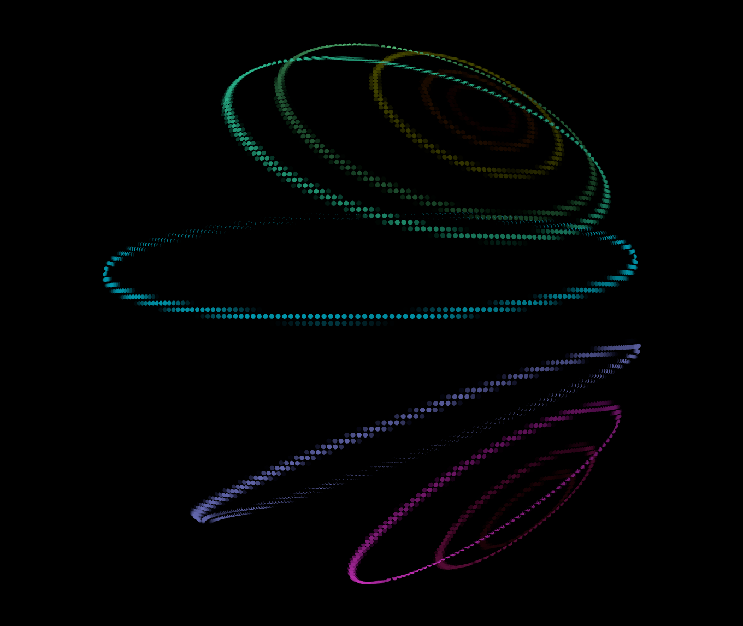
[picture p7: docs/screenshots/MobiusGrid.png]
MobiusGrid
<td width="300"></td>
<td valign="top">

#### MobiusGrid

A latitude-longitude grid that undergoes live Möbius transformation animation via `MobiusWarpCircularTransformer`.

**Parameters**: Rings, Lines, Alpha

</td></tr></table>

<table border="0"><tr>
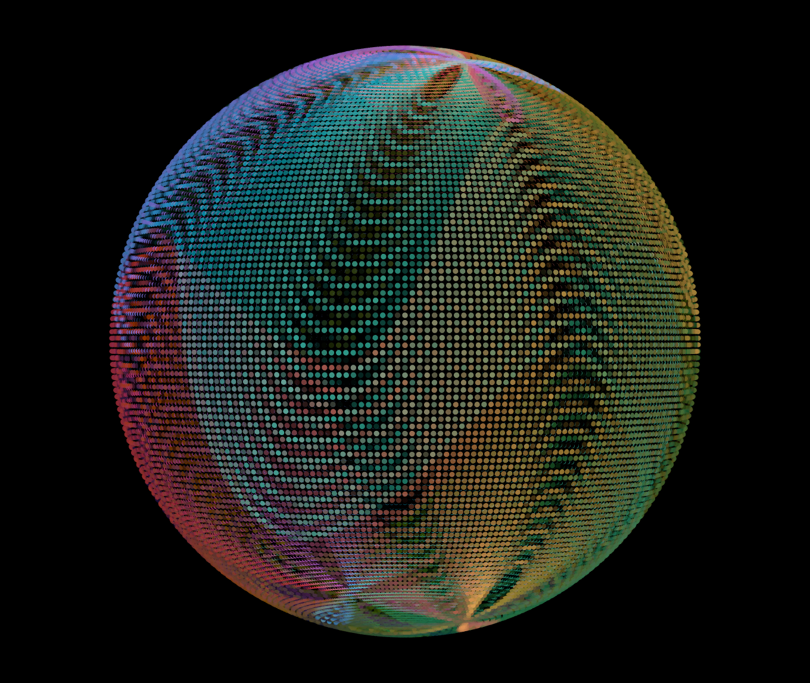
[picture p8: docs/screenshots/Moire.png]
Moire
<td width="300"></td>
<td valign="top">

#### Moire

Two counter-rotating families of concentric rings that beat against each other into a shifting moiré interference pattern, driven by an animated ring-distortion amplitude.

</td></tr></table>

<table border="0"><tr>
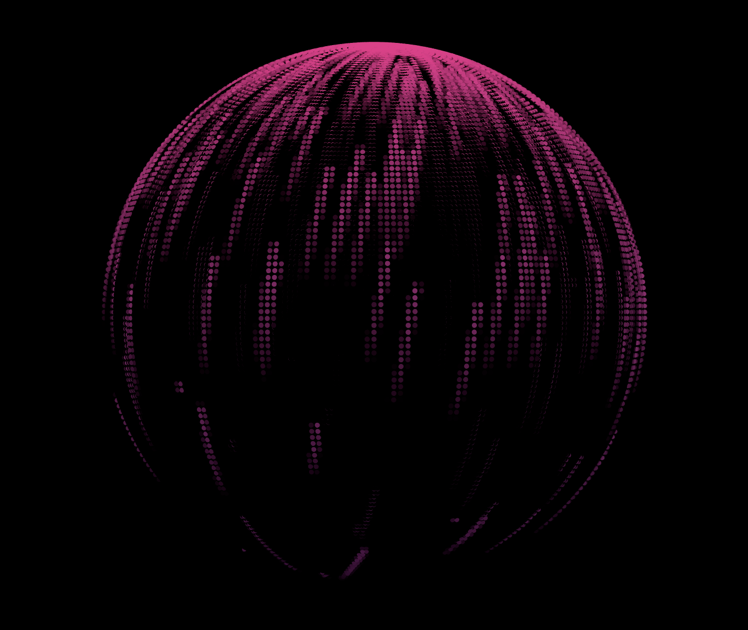
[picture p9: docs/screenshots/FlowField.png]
FlowField
<td width="300"></td>
<td valign="top">

#### FlowField

FastNoiseLite-driven flow field. Three independently offset 3D-noise channels form a per-particle force vector that is added to each particle's velocity (not curl noise, not a scalar gradient).

**Parameters**: Scale, Force, Max Spd, Alpha, Time Spd

</td></tr></table>

<table border="0"><tr>
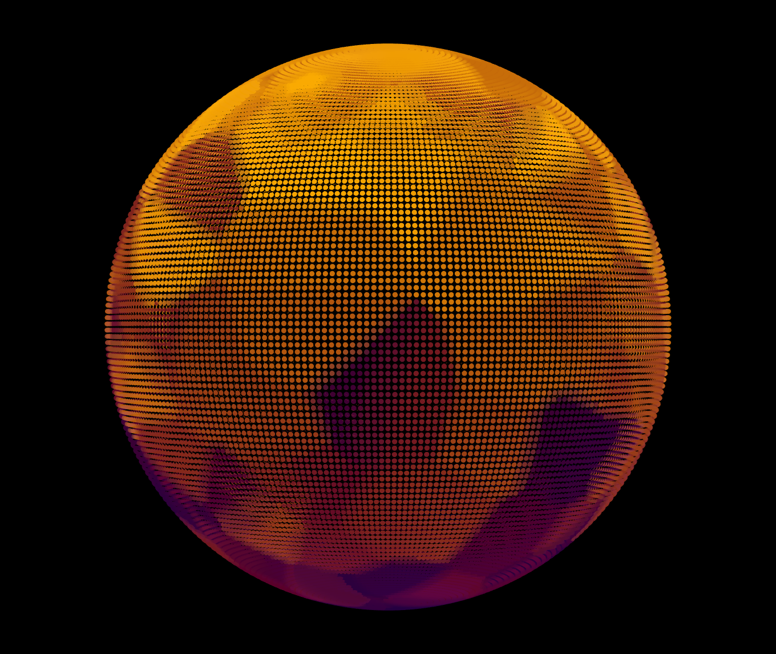
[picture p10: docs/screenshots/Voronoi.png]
Voronoi
<td width="300"></td>
<td valign="top">

#### Voronoi

Spherical Voronoi diagram with animated seed positions. Cells are always filled with per-site palette colors (smoothly blended across the seam between the nearest two sites); an optional black border seam is painted between neighboring cells when **Border Thick** > 0 (off by default).

**Parameters**: Num Sites, Speed, Sharpness, Border Thick

</td></tr></table>

<table border="0"><tr>
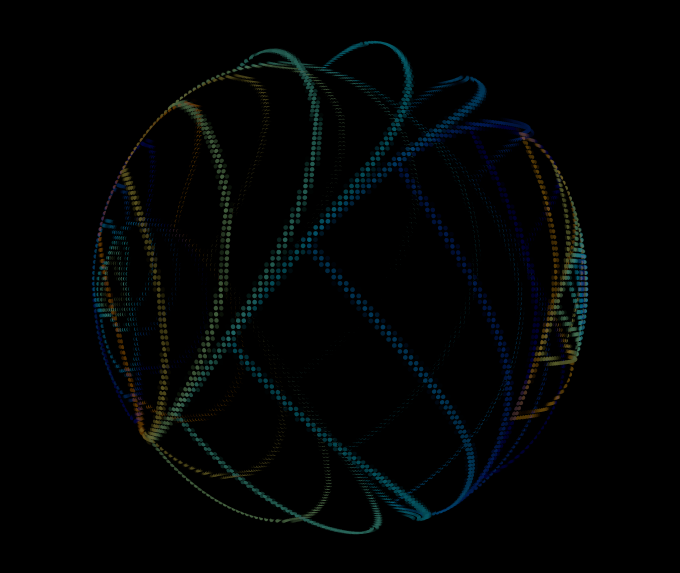
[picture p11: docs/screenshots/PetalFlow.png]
PetalFlow
<td width="300"></td>
<td valign="top">

#### PetalFlow

Polyline rings drift pole-to-pole through an inverse stereographic projection, each wobbled into petal lobes and twisted by an angle that grows with its position; rasterized via Plot.

</td></tr></table>

<table border="0"><tr>
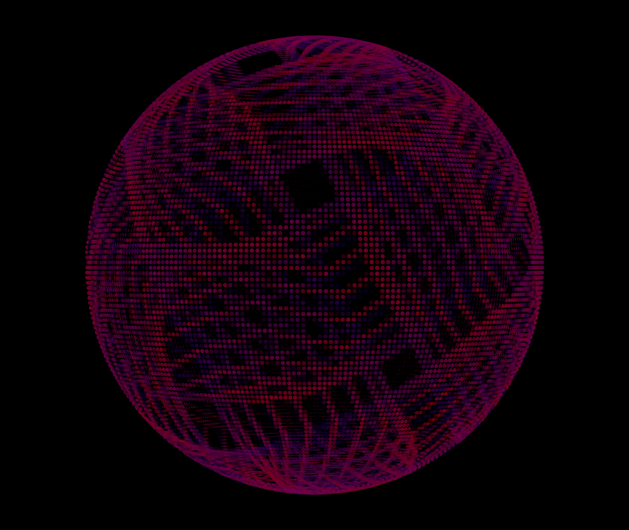
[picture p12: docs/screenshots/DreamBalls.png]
DreamBalls
<td width="300"></td>
<td valign="top">

#### DreamBalls

Draws twisting wireframe knotted structures derived from Archimedean solids. Mesh vertices are displaced along per-vertex tangent frames to create orbiting knot patterns, and a Möbius warp is applied to the geometry. Multiple copies orbit simultaneously while the whole structure tumbles under a slow Languid random-walk view orientation punctuated by periodic full-sphere spins.

**Parameters**: Copies (number of knot copies), Radius (displacement), Speed (orbit speed), Warp (Möbius warp scale), Alpha

</td></tr></table>

<table border="0"><tr>
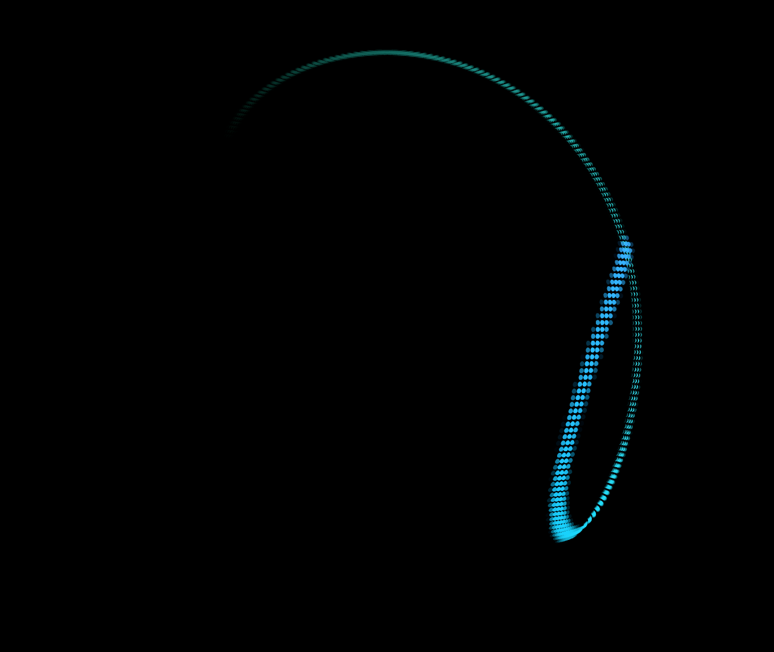
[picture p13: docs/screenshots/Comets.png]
Comets
<td width="300"></td>
<td valign="top">

#### Comets

A single head traces spherical Lissajous curves, cycling through a dozen configurations, trailed by a long 115-frame orientation tail and periodically wiping the palette to a fresh triadic scheme.

</td></tr></table>

<table border="0"><tr>
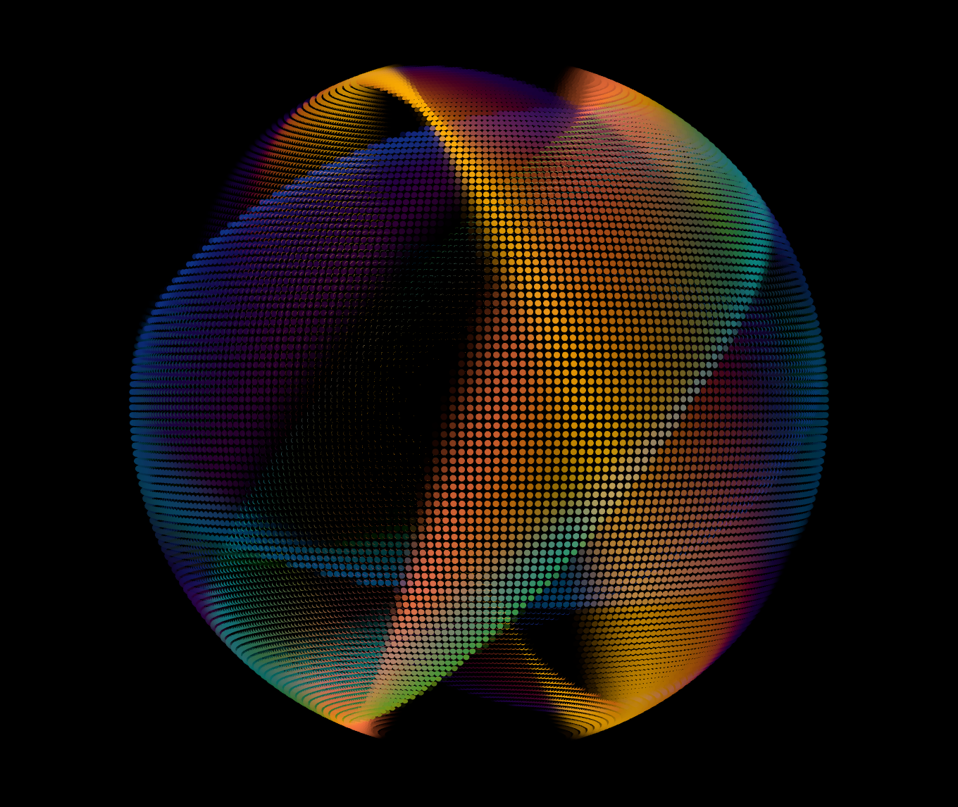
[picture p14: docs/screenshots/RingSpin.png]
RingSpin
<td width="300"></td>
<td valign="top">

#### RingSpin

Four great-circle rings tumble continuously under energetic random-walk rotation, each leaving a fading motion-blur trail of its recent orientations (drawn with `Scan::Ring`, head and tail of the trail thickened). Each ring is colored by a baked vignette palette.

**Parameters**: Alpha, Thickness, Show Bounding

</td></tr></table>

<table border="0"><tr>
<td width="300"><a href="https://woundedlion.github.io/daydream/?effect=RingShower" target="_blank">RingShower</a></td>
<td valign="top">

#### RingShower

Rings bloom at random orientations and grow their radius from zero, fading in over the first few frames and then holding (no fade-out), colored by a generative circular analogous palette — a continuous shower of expanding rings drawn with `Plot::Ring`. Each ring's radius, fade, and lifetime are pure functions of its age driven directly from a recyclable slot rather than a per-ring `Sprite`.

**Parameters**: Alpha

</td></tr></table>

<table border="0"><tr>
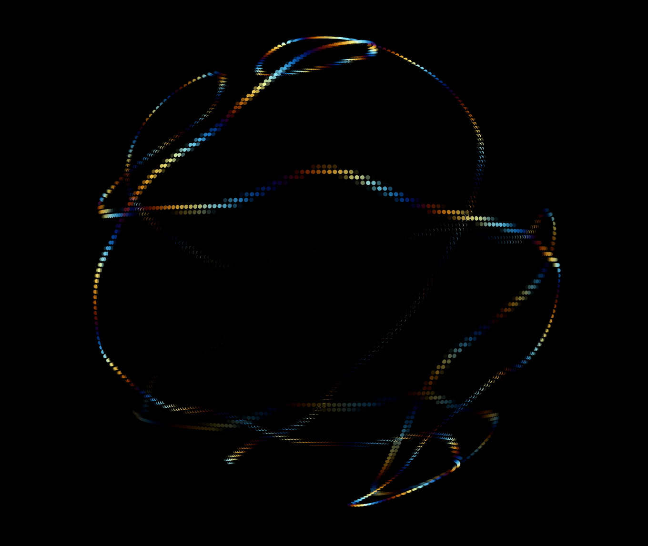
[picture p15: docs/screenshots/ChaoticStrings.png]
ChaoticStrings
<td width="300"></td>
<td valign="top">

#### ChaoticStrings

A head traces a fixed 12:5 spherical Lissajous figure whose long trail is continuously warped by a noise transformer, over a slowly cycling gradient palette.

</td></tr></table>

<table border="0"><tr>
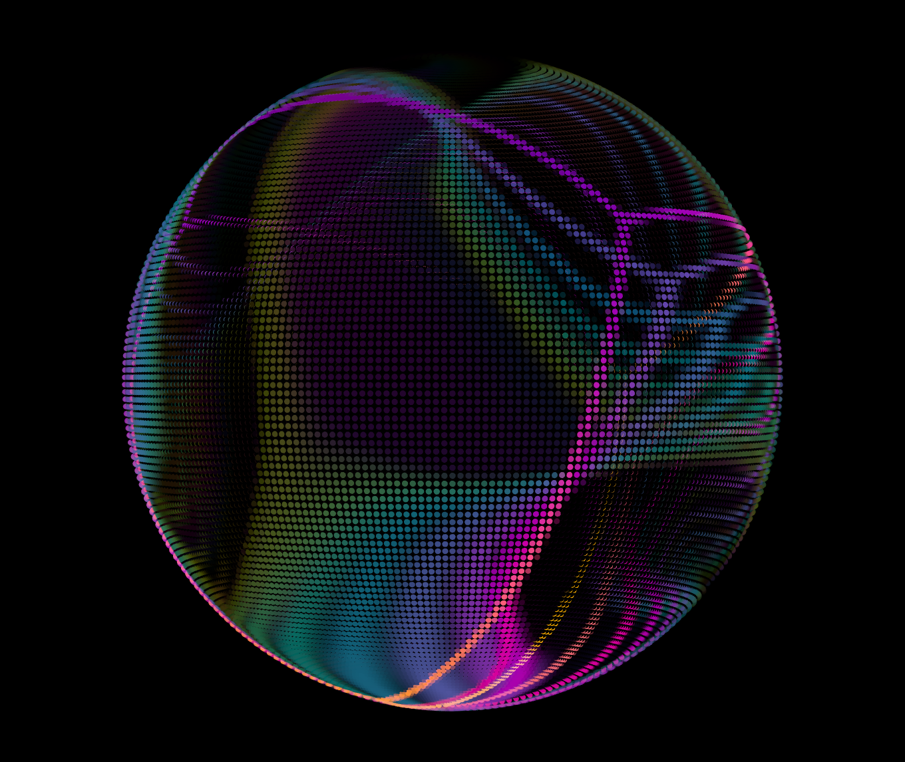
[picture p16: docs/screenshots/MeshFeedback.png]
MeshFeedback
<td width="300"></td>
<td valign="top">

#### MeshFeedback

Platonic solid mesh faces rendered with `Plot::Mesh`, given a noise-distorted, feedback-loop appearance via `Filter::Pixel::Feedback`. Cycles through the Platonic solid library, crossfade-morphing between shapes with `Animation::MeshMorph`, while a `Presets` cycle hard-cuts the feedback/distortion style parameters.

</td></tr></table>

<table border="0"><tr>
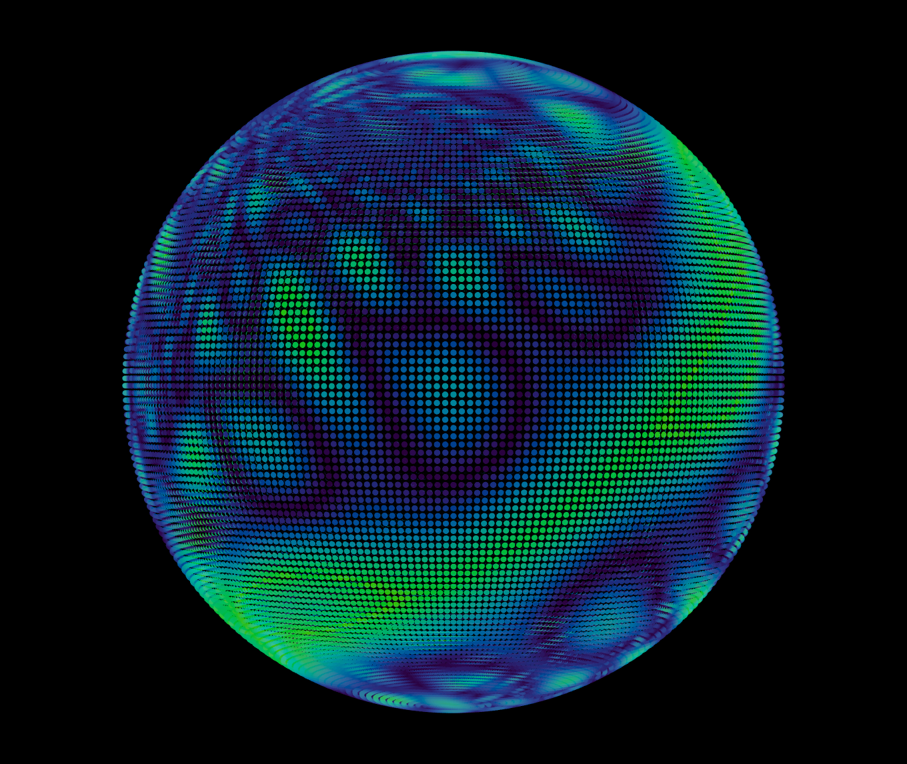
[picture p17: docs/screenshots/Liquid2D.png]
Liquid2D
<td width="300"></td>
<td valign="top">

#### Liquid2D

Stereographic-projection shader (extends `Effect` directly) that samples world-space through a configurable glitch lens (hemisphere mirror + squish/warp). Dual random-walk orientations animate the view and global rotation independently, producing flowing liquid distortion. Uses `Scan::Shader::draw` for full-screen pixel shading and `StaticPalette` with a `BreatheModifier` for animated palette cycling.

**Parameters**: Warp Scale, Warp Strength, Pattern Freq, Time Speed, Complexity, Pole Fade, Cycle Speed

</td></tr></table>

<table border="0"><tr>
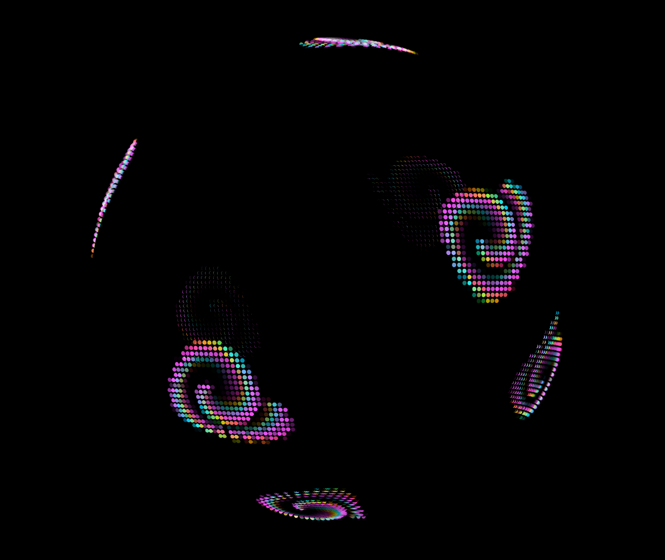
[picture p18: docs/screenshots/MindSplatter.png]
MindSplatter
<td width="300"></td>
<td valign="top">

#### MindSplatter

Random-walk particle system with Möbius warp bursts.

</td></tr></table>

<table border="0"><tr>
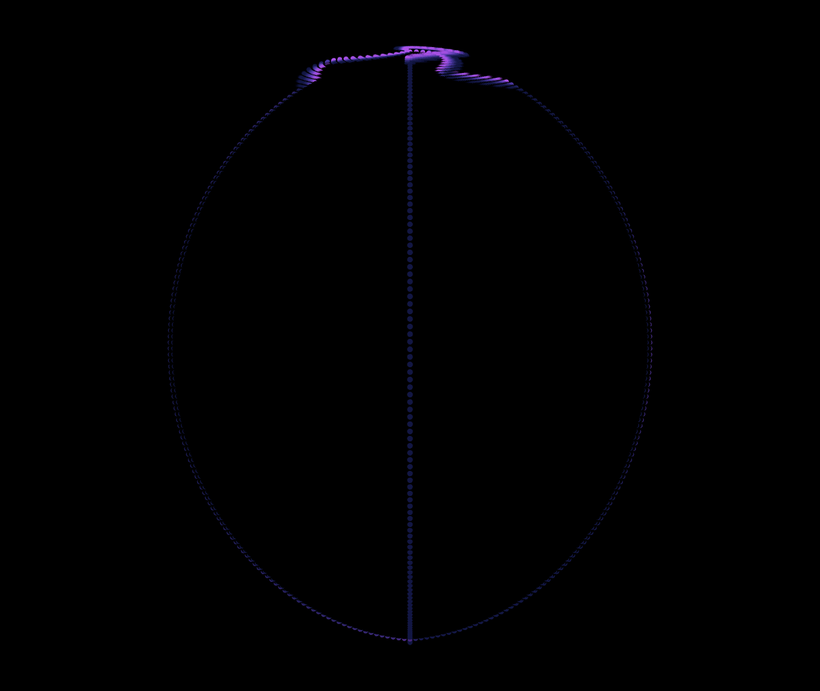
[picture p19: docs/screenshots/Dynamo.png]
Dynamo
<td width="300"></td>
<td valign="top">

#### Dynamo

A vertical strand of points — one per latitude row — drifts horizontally around the sphere, each row dragging the next under a gap constraint so the chain wavers like a wind-blown curtain. The strand leaves motion trails, is replicated three times around the sphere, periodically reverses direction, and tumbles under random-axis rotations, while periodic color wipes sweep freshly generated analogous palettes across it.

**Parameters**: Speed, Gap, Trail Len, Wipe Dur

</td></tr></table>

<table border="0"><tr>
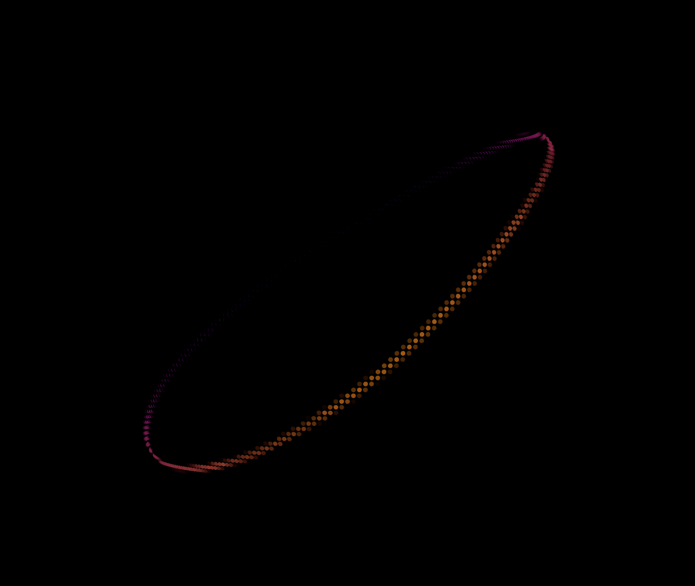
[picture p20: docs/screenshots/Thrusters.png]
Thrusters
<td width="300"></td>
<td valign="top">

#### Thrusters

A central distorted ring (`Plot::DistortedRing`) warps and spins; periodic random "fires" kick it onto a new axis and bloom a pair of opposed thrust rings (`Plot::Ring`) that expand from zero and fade out.

**Parameters**: Radius, Alpha

</td></tr></table>

<table border="0"><tr>
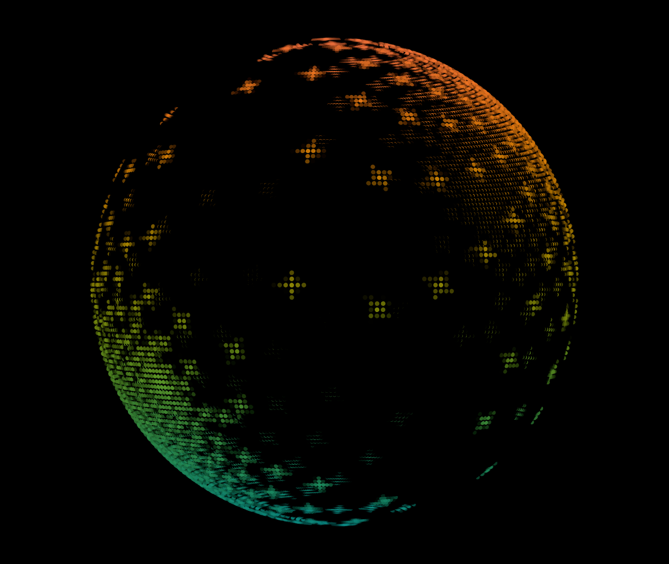
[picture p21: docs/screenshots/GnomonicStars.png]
GnomonicStars
<td width="300"></td>
<td valign="top">

#### GnomonicStars

A Fibonacci-spiral field of star-polygon SDFs, continuously deformed by an evolving Möbius warp (built on a gnomonic-projection transformer) and slowly tumbled by a Languid random walk.

</td></tr></table>

<table border="0"><tr>
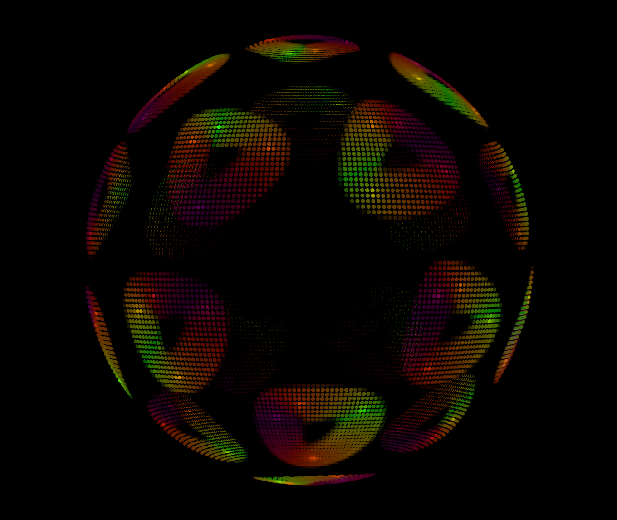
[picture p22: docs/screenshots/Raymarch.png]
Raymarch
<td width="300"></td>
<td valign="top">

#### Raymarch

Volumetric raymarcher that renders twisted tori at the 20 vertices of a dodecahedron. Each torus is ray-marched with `Scan::Volume::draw` and lit with metallic Blinn-Phong shading (half-Lambert diffuse, specular highlights, Fresnel rim). A random-walk animation drives the camera orientation.

**Parameters**: Pulse Speed, Core Size, Max Steps, Diffuse, Specular, Fresnel, Twist, AA Width

</td></tr></table>

<table border="0"><tr>
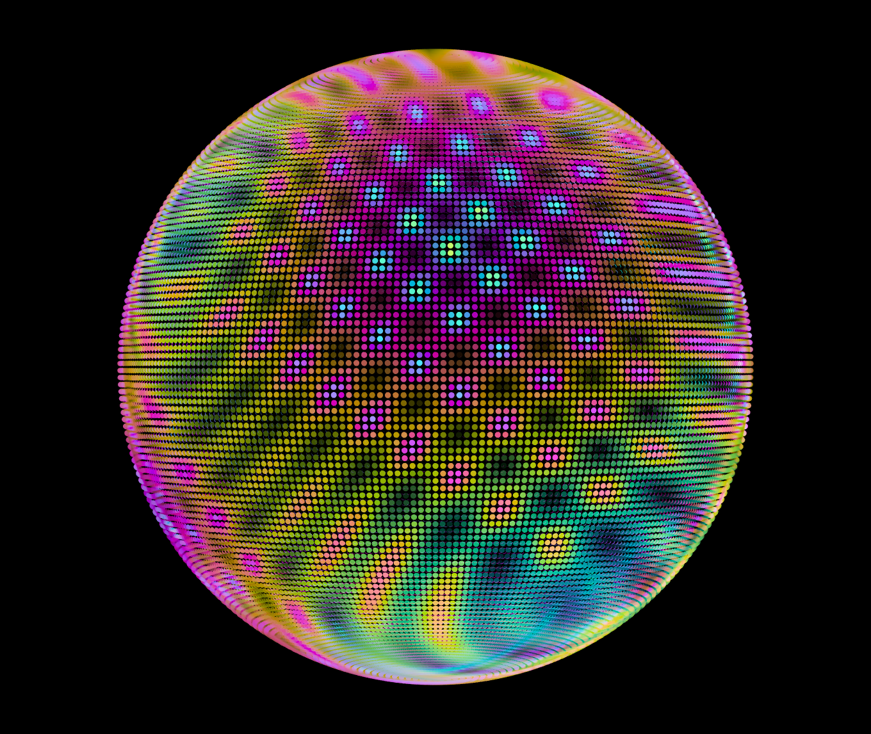
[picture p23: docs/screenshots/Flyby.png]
Flyby
<td width="300"></td>
<td valign="top">

#### Flyby

Stereographic-projection shader (extends `Effect` directly) with noise-driven warp distortion. A single `Rotation` animation continuously rotates the tangent plane around the Y-axis, producing a fly-through effect on the sphere surface. Uses `Scan::Shader::draw` for full-screen pixel shading with a baked palette.

**Parameters**: Warp Scale, Warp Strength, Pattern Freq, Speed, Pole Fade, Drift, Hue Shift

</td></tr></table>

<table border="0"><tr>
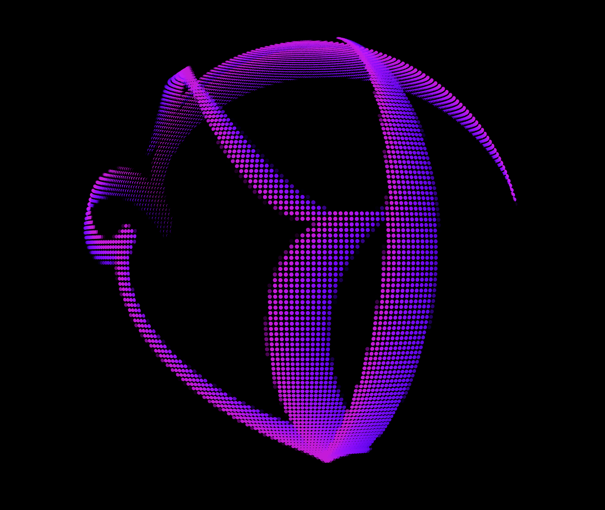
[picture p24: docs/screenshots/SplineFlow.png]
SplineFlow
<td width="300"></td>
<td valign="top">

#### SplineFlow

Catmull-Rom spline curves whose control points drift via independent random walks. Drawn with `Plot::SplineChain` in closed-loop mode through `World::Trails` for persistent trails, producing flowing organic ribbon paths.

**Parameters**: Tension, Speed, Drift, Num Pts, Alpha

</td></tr></table>

The two effects below are registered and selectable but not pictured here:

#### DistortedRing

Concentric rings built from per-azimuth distorted ring SDFs, their radii oscillating via a sine-wave amplitude mutation while a random walk slowly reorients the stack.

**Parameters**: Alpha, MaxAmplitude, Thickness, Rings, Show Bounding

#### ShapeShifter

Layered polygon, star, and flower rings (planar and spherical polygon variants) drawn through both the `Plot` and `Scan` rasterizers at once. The shape type hard-cuts to the next of four (planar polygon, spherical polygon, flower, star) every 48 frames while a twist Mutation shears the layers. All `Plot` rings share one tumbling orientation and all `Scan` rings share another, so layer Count scales with the raster budget rather than the timeline.

**Parameters**: Alpha, Count, Radius, Sides, Twist, Debug BB

### Legacy Effects (`effects_legacy.h`)

TheMatrix, ChainWiggle, RingRotate, RingTwist, Curves, Kaleidoscope, StarsFade, DotTrails, Burnout, Fire, Spinner, Spiral, WaveTrails, RingTrails — built before the current engine and using an older rendering API. Functional but not representative of current architecture.

---

## 10. The Web Simulator (Daydream)

The [`daydream`](https://github.com/woundedlion/daydream) repo is a static web app that wraps the WASM build from this repo in a Three.js scene. The C++ rendering engine is unchanged — the same effect classes, the same arenas, the same per-frame `Pixel16[]` buffer. Daydream's job is to:

1. Drive the WASM engine one frame at a time at a fixed cadence.
2. Map each `(x, y, color)` pixel to a position on a 3D sphere and render it as an instanced dot mesh.
3. Provide a UI for switching effects, tuning parameters, sweeping resolutions, recording video, and exercising the segmented-POV multi-board mode.
4. Host five standalone geometry tools that reuse the engine's `MeshOps` for interactive design work.

### 10.1 Process and Threading Model

```
Main thread                                Web Workers (segment mode only)
─────────────                              ──────────────────────────────
index.html → vendor-importmap.js           segment_worker.js × N
              ↓ (resolves three/lil-gui    each owns its own WASM module
              ↓  to local or CDN)
            daydream.js (entry)            engine.setClip(x0,x1,y0,y1)
              ├─ createHolosphereModule()  engine.drawFrame()  → pixel slice
              ├─ Daydream (driver.js)      postMessage(Transfer pixels)
              │    ├─ Three.WebGLRenderer
              │    ├─ instanced dot mesh
              │    ├─ OrbitControls
              │    └─ PiP camera
              ├─ AppState + URLSync
              ├─ EffectSidebar
              ├─ lil-gui (params + global)
              └─ VideoRecorder (MediaRecorder)
```

A normal page load creates one WASM instance on the main thread. The dot mesh has one instance per LED pixel; the per-frame work is `instanceColor.needsUpdate = true` after the WASM buffer view is refreshed. When the user enables Segmented POV (§10.5), `daydream.js` spawns N Web Workers, each holding its own WASM module so the four-Teensy Phantasm layout can be exercised in software.

### 10.2 The WASM Bridge

`wasm.cpp` compiles to `holosphere_wasm.js` + `.wasm` and exposes a single `HolosphereEngine` class:

| Method | Description |
|---|---|
| `setResolution(w, h)` → `bool` | Switch active resolution (96×20 or 288×144); returns `false` on an unsupported size |
| `setEffect(name)` → `bool` | Instantiate a new effect by string name; resets all arenas to defaults; returns `false` on an unknown name |
| `drawFrame()` | Advance one frame and copy pixels to the output buffer |
| `getPixels()` | Return a zero-copy `Uint16Array` view into WASM linear memory |
| `getBufferLength()` → `int` | Length of the pixel buffer (`W × H × 3`) for sizing the view |
| `setParameter(name, value)` → `bool` | Update a live effect parameter; returns `false` on an unknown name |
| `setAnimationsPaused(paused)` | Freeze/resume the current effect's animation drivers (the GUI "Pause Animation" toggle) |
| `getParameterDefinitions()` | Return the parameter list; each entry is `{name, value, animated, readonly}`, and float params additionally carry `{min, max}` (bool params omit `min`/`max` and return `value` as a JS boolean) |
| `getParamValues()` | Return current parameter values (including animation-driven updates) |
| `getArenaMetrics()` | Memory usage stats for geometry, scratch, and tooling arenas, plus the stack high-water mark (see below) |
| `getEffectSizes()` | Return `sizeof` for every registered effect at the current resolution |
| `getSupportedResolutions()` → `[[w, h], …]` | *(static)* List the resolutions the build supports, as `[width, height]` pairs |
| `setClip(x0, x1, y0, y1)` → `bool` | Restrict rendering to a sub-rectangle (used by segment workers) |
| `getRenderUs()` → `double` | Last frame's rasterization time in microseconds (per-frame profiling) |

The bridge also exposes a `MeshOps` class — used by the `solids.html` geometry tool — with dedicated tooling arenas (an 8 MB persistent arena plus two 4 MB scratch arenas — 16 MB total, separate from the engine's 330 KiB arena) for interactive solid manipulation.

Alongside the classes, the bridge exports a few free spline-evaluation functions — `spline_cubic_fast`, `spline_cubic_slerp`, and `spline_catmull_rom_tangents` — used by the `splines.html` tool so its Bézier / Catmull-Rom curves are evaluated by the same engine code the firmware uses rather than a JavaScript reimplementation.

The WASM bridge includes stack high-water-mark instrumentation: `stack_paint_canary()` fills the stack with a known pattern at init time, and `stack_high_water_mark()` scans for the deepest overwrite. This is reported via `getArenaMetrics()` and logged on every effect switch to catch stack-hungry template instantiations early.

Pixel data is 16-bit linear light (`uint16_t` per channel). The zero-copy `Uint16Array` view is bound directly as the instanced dot-mesh's `instanceColor` attribute, declared `normalized` so Three.js scales 0–65535 → 0–1 linear **on the GPU** — there is no per-pixel divide or float copy in JavaScript (Three.js expects linear color when `THREE.ColorManagement.enabled = true`):

```js
const wasmPixels = wasmEngine.getPixels();   // Uint16Array view, zero-copy
// Bound once as the instance-color buffer; the `true` flag marks it normalized,
// so the GPU divides by 65535 on read. No JS-side divide or Float32 copy.
dotMesh.instanceColor =
    new THREE.InstancedBufferAttribute(wasmPixels, 3, /*normalized=*/ true);
// → instanced dot-mesh per-instance colors → WebGL renderer
```

### 10.3 The Three.js Renderer (`driver.js`)

The `Daydream` class owns the entire render side. Features:

| Feature | Details |
|---|---|
| **Instanced dot mesh** | One `InstancedMesh` of `W × H` small spheres. Per-instance position is precomputed in `setupDots()` from `pixelToVector(x, y)`; per-instance color is updated each frame from the WASM pixel buffer. Single draw call per frame. |
| **Linear color pipeline** | `THREE.ColorManagement.enabled = true` and `setPixelRatio(min(devicePixelRatio, 1))`. Colors arriving from WASM are already linear, so no extra conversion. |
| **OrbitControls camera** | A normal `PerspectiveCamera` at `(0, 0, 220)` with FOV 20°, plus `OrbitControls` for mouse/touch navigation. |
| **Picture-in-picture** | A clone of the main camera at a fixed orientation renders to a 30%-sized bottom-right viewport so the front and back of the sphere are visible simultaneously. Suppressed when `isMobile` or `navigator.webdriver` (§ headless capture). |
| **Axes overlay** | Three `THREE.Line`s for X/Y/Z visible on toggle, plus a `CSS2DRenderer`-backed `LabelPool` for "+X / +Y / +Z" labels with zero allocation per frame. |
| **Resize observer** | `ResizeObserver` on the canvas container recomputes camera aspect, viewport, and `isMobile` (width ≤ 900). |
| **Fixed-rate stepping** | The simulation ticks at `1/FPS` seconds independent of the actual render rate, with a time accumulator to keep effects deterministic. |

### 10.4 Application State (`state.js`)

Daydream uses a tiny pub/sub state container plus a URL-syncing wrapper:

```js
const appState = new AppState({ effect: 'IslamicStars', resolution: 'Phantasm (144x288)' });
new URLSync(appState, ['effect', 'resolution']);  // mirrors keys to query string

appState.subscribe((key, value, old) => {
  if (key === 'effect') applyEffect();
  else if (key === 'resolution') applyResolution();
});
```

- **`AppState`** — flat key→value store with a `subscribe(callback)` API. Setting a key fires the callback only if the value actually changed. The sidebar and lil-gui both write through `appState.set(...)`, so they stay in sync without explicit coupling.
- **`URLSync`** — reads tracked keys from `window.location.search` on construction (URL beats default), then debounces writes back to the query string via `history.replaceState`. Shareable links like `?effect=Raymarch&resolution=Phantasm%20(144x288)` work out of the box.
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

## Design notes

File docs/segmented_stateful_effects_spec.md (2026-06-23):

# Stateful Effects in Segmented Mode — Design Spec

*Status: IMPLEMENTED. This document describes the design — now in the engine —
for making history-reading pixel effects (today only `MeshFeedback`, via the
`Pixel::Feedback` filter) render correctly under the simulator's segmented
mode, without dropping pixels, while non-stateful effects keep the full
clipping win. The seam is the WASM driver boundary (`targets/wasm/wasm.cpp`
`setClip`) plus two compile-time filter traits; the device path is already
correct and does not change.*

---

## 1. Goal

`MeshFeedback` — and any future effect whose per-frame state depends on
*other segments'* pixels — must produce identical output whether rendered as
one full-canvas instance or as N segment workers. Non-stateful effects must
retain segmented rendering's clipping win (out-of-band pixels never shaded).

---

## 2. Where segmentation actually lives

Segmentation-by-clipping is a **simulator-only** mechanism. The two render
paths diverge:

- **Device (`hardware/pov_segmented.h`).** Every Teensy renders the *full*
  `CANVAS_W × CANVAS_H` canvas (`cur->draw_frame()`, pov_segmented.h:321).
  The flywheel ISR's `render_column()` (pov_segmented.h:631) packs only this
  board's LEDs out of the full buffer via `pov::segment_x_col()`. There is no
  `set_clip` on the device. `MeshFeedback` is therefore **already correct in
  hardware** — each board independently computes the whole frame and samples
  its slice.

- **Simulator (`segment_worker.js` → `targets/wasm/wasm.cpp`).** Daydream
  reproduces the *partitioning* in software: one isolated WASM module instance
  per segment, each calling `setClip(x0, x1, y0, y1)` (wasm.cpp:465) so the
  rasterizer's scanline culling skips out-of-clip rows/columns. The readback
  copies the full canvas; `segment_worker.js` then extracts just the quadrant
  rectangle (`blitSegmentRect`) before transfer (README §10.7).

So "compute the full frame per segment" is **what the device already does**.
The simulator's clipping is an optimization that is sound for non-stateful
effects and *wrong* for unbounded-reach feedback.

---

## 3. Why clipping drops pixels for feedback

The feedback flush iterates only the clip band (filter.h:1487) but reads
`cv.prev` at warp offsets up to **±W/2 horizontally and ±H vertically**
(filter.h:1436 — a melt/swirl warp can pull a row most of the way across the
canvas). That reach is **unbounded relative to a segment band**: a worker
clipped to its band has stale or zero `prev` outside the band, so cross-band
trails read as black → dropped pixels and visible seams at the band edges.

Two consequences, both load-bearing for the design:

1. **The flush must run full-frame.** Correct output in a band requires a
   correct full prior frame, which requires the flush to have advanced the
   whole canvas last frame — recursively, every frame.

2. **The mesh draw must also run full-frame.** The mesh is the *source* that
   seeds the trails. If a worker skips drawing the mesh outside its band, the
   warp pulls that missing content into the band over successive frames, and
   the band's own display loses trail content that originated elsewhere.

There is therefore **no per-worker rasterization win for an unbounded-reach
feedback effect** — both the flush and its source draw are inherently
full-frame. The clipping win survives only for (a) non-stateful effects
(clip everything) and (b) the per-segment output slice, which is already done
JS-side and shades nothing. This is not a limitation of the design; it is the
same cost the device pays for distributed memory, and segmented WASM currently
*violates* the sim-mirrors-device invariant by pretending otherwise.

A finer reach distinction still matters for *other* history filters
(§5): `Screen::Trails` decays pixels in place (reach 0 — band clipping is
already correct), whereas `Pixel::Feedback` (warp) and `World::Trails`
(reprojected under rotation) move content across bands.

---

## 4. Design

### 4.1 Derive cross-segment reach as a compile-time trait

Statefulness is already a compile-time filter trait (`has_history`, with the
`Pipeline` constexpr-folding the history/terminal static-asserts at
filter.h:350). Add a sibling trait that captures the property that actually
matters here — whether a filter's state *moves across segment boundaries*:

- `static constexpr bool crosses_segments`, defaulting to `has_history`
  (fail-safe: a new history filter is treated as cross-segment until proven
  bounded). Add it to the four trait bases (`Is2D`/`Is3D`/`Is2DWithHistory`/
  `Is3DWithHistory`, filter.h:49) as `= has_history`.
- `true` on `Pixel::Feedback` — the load-bearing case, and the only one that
  *must* be `true`. It reads `cv.prev` (other segments' pixels).
- `true` on `World::Trails` — already `true` by default (`has_history`), so
  this is documentation, not a required override. Its store happens at
  `plot()` time (filter.h:778), upstream of projection; whether band clipping
  would actually corrupt it depends on whether the rasterizer culls
  out-of-band fragments *before* that store. Left `true` as the fail-safe
  default rather than relying on that analysis.
- `false` on `Screen::Trails` — the **only non-fail-safe override**: it turns
  full-frame *off* for a history filter, justified solely by reach 0 (decays
  in place, redraws at the same screen coordinate). If that reasoning is
  wrong, it drops pixels — so it must be tested directly (§8).

`Pipeline` does **not** today expose any aggregate trait constant — the
existing folding is per-node recursive `static_assert`s on `Head::has_history`
(filter.h:350), nothing more. So this trait needs a new recursive OR-fold
written from scratch: `static constexpr bool any_crosses_segments =
Head::crosses_segments || NextPipeline::any_crosses_segments;` in the recursive
node, **plus a `false` base case in the terminal `Pipeline<W,H>`**
(filter.h:111). There is no existing `any_*` member to mirror.

### 4.2 Expose it as one runtime query on `Effect`

```
virtual bool needs_full_frame() const { return false; }
```

There is no shared base hook — each effect that wants the gate adds the
override itself:

```
bool needs_full_frame() const override {
  return decltype(filters)::any_crosses_segments;
}
```

The override's *value* is fully trait-derived (no per-effect judgment): it reads
the pipeline's compile-time `any_crosses_segments` fold, so adding or removing a
filter updates the answer automatically. Only the one-line bridge is manual,
because `Effect` is type-erased — the driver holds an `Effect*` and the compile-
time fold lives only in the derived effect's `filters` member, so a base virtual
cannot read it without the derived type surfacing it. Going fully implicit would
mean reparenting every filtered effect onto a CRTP base that reads
`Derived::filters`, which also has to reach each effect's (private) `filters` —
strictly more intrusive than the one-liner, so it is not done.

Every effect whose pipeline crosses segments carries the identical override:
`MeshFeedback` (`Pixel::Feedback`) and the two `World::Trails` effects `Dynamo`
and `SplineFlow` (→ `true`). Everything else stays `false` by default. The
roster test (§8) pins exactly this set so a new cross-segment effect that forgets
the override is caught.

### 4.3 Honor it at the driver boundary (the only behavioral change)

In `targets/wasm/wasm.cpp` `setClip` (wasm.cpp:449): if
`currentEffect->needs_full_frame()`, leave the clip at the full canvas
(optionally record the requested band for telemetry) and return; otherwise
apply the band as today.

"Leave at full" is safe because the clip is already full when this fires: the
`Effect` constructor resets `clip` to the whole canvas (canvas.h:58), and the
worker re-applies the band *only* after `setEffect` rebuilds the effect
(`segment_worker.js` `applyClip`). So a full-frame effect's clip is never
narrowed in the first place — the early return preserves the constructor's
full clip rather than relying on resetting a stale band. (If that lifecycle
ever changes, harden this to an explicit `set_clip(0, H, 0, W)` instead.)

The elegance is that **the hot-path filter code needs no change**. With a
full clip, `XClip::active` is false and the coarse-row band spans every row,
so the flush's existing band-pruning (filter.h:1448, filter.h:1597) already
degrades to full-frame — the comments there note "a full canvas... does the
same work either way." `blitSegmentRect` still slices each worker's quadrant
from the full readback, unchanged. Every worker computes the bit-identical
full frame; only the slice differs — matching the device exactly.

**Precondition (existing invariant this rests on).** "Bit-identical full
frame across workers" holds only because per-worker frame inputs are already
deterministic: animations are *frame-stepped*, not wall-clock-stepped
(`AnimationBase::step` counts frames; `drawFrame()` advances exactly one,
wasm.cpp:501 — the `elapsed`/`renderUs` timings are telemetry and never feed
animation), the RNG is fixed-seed (`std::mt19937(1337)`), and params are
broadcast to every worker. The same invariant non-stateful segmented effects
already depend on; the design adds nothing new to it but is wholly dependent
on it.

### 4.4 Reuse dormant `set_margin` for the bounded tier

`set_margin` (canvas.h:127) exists but is exercised only in a test
(test_canvas.h:461). It is the home for the genuine "clip rasterization to
save time" case that *does* apply to neighborhood-reading effects: a bounded
spatial reach (AntiAlias ±1, small blurs) renders band + a declared margin
instead of full-frame. `MeshFeedback` is unbounded and skips this tier.

---

## 5. Policy summary

| Effect class | Reach | Simulator render bound |
|---|---|---|
| Non-stateful | none | segment band (+1 AA margin) — full clipping win |
| In-place history (`Screen::Trails`) | 0 (redraws at same coord) | segment band — no margin needed; `crosses_segments = false` |
| Bounded spatial neighborhood (AntiAlias ±1, small blurs) | finite | band + declared `set_margin` (§4.4, future) |
| Cross-segment history (`Pixel::Feedback`, `World::Trails`) | unbounded | full canvas; output sliced JS-side |

---

## 6. What changes, what does not

| Layer | Change |
|---|---|
| `core/filter.h` traits | add `crosses_segments = has_history` to the trait bases; `false` on `Screen::Trails`; add a **new** recursive `any_crosses_segments` OR-fold to `Pipeline` + a `false` base case in the terminal `Pipeline<W,H>` (no existing `any_*` to mirror) |
| `core/canvas.h` `Effect` | add `needs_full_frame()` virtual (default `false`) |
| `targets/wasm/wasm.cpp` `setClip` | branch on `needs_full_frame()` → full canvas vs band |
| flush / `scan.h` / `plot.h` hot paths | **none** — a full clip already degrades correctly |
| `hardware/pov_segmented.h` (device) | **none** — already full-frame |
| `segment_worker.js` slicing | **none** |

---

## 7. Open decision: redundant workers vs single-instance

The design above runs **N redundant, identical full-frame workers** for a
stateful effect. It is the simplest path, mirrors the device's independent
per-board compute, and is bit-identical to it.

The alternative: because all N workers compute the bit-identical frame for a
cross-segment effect, render it **once** and let all quadrants slice that
single readback, recovering the (N−1)× browser compute. This is faster in the
simulator but diverges the sim's topology from the device (hardware genuinely
has N independent computes) and complicates worker orchestration (a mixed
segmented / single-instance mode keyed on `needs_full_frame()`).

**Recommendation:** take the redundant-workers path, consistent with the
project's sim-mirrors-device doctrine. The single-instance variant is the
lever to pull only if browser cost during stateful effects outweighs
topological fidelity.

---

## 8. Test plan

Implemented in `tests/test_filter.h` and `tests/test_effects.h`:

- **Trait fold** (`test_crosses_segments_trait_and_fold`, test_filter.h): pins
  the per-filter `crosses_segments` values (incl. the `Screen::Trails == false`
  override) and the `Pipeline::any_crosses_segments` OR-fold — `true` for the
  MeshFeedback stack, `false` for a non-stateful stack and a `Screen::Trails`
  stack — so a future filter addition can't silently regress the gate.
- **Roster gate** (`test_needs_full_frame_gate`, test_effects.h): constructs the
  real effects and asserts `needs_full_frame()` is `true` for exactly the
  cross-segment set (`MeshFeedback`, `Dynamo`, `SplineFlow`) and `false` for
  representative non-stateful effects. This is the end-to-end equivalent of a
  `setClip` test — the WASM driver reads exactly this query, and `setClip` itself
  lives in the Emscripten-only TU, which the native suite cannot link. A new
  cross-segment effect that forgets the override is caught here.
- **`Screen::Trails` banded-vs-full bit-identity**
  (`test_screen_trails_banded_matches_full`, test_filter.h): the load-bearing
  proof of the one non-fail-safe override. The same multi-frame seed sequence is
  driven through one full-canvas instance and two band-clipped instances; the
  stitched banded output must equal the full output byte-for-byte. This is the
  override that drops pixels if the reach-0 reasoning is wrong.
- **Feedback band-clip divergence**
  (`test_feedback_banded_diverges_from_full`, test_filter.h): the inverse for an
  unbounded-reach filter — a melt warp drips content across the segment boundary,
  so a band-clipped `Pixel::Feedback` worker's bottom band differs from the
  full-frame render. Demonstrates *why* full-frame is required: band clipping
  here is not equivalent, so the gate is load-bearing, not cosmetic.
- `test_effect_needs_full_frame_default_false` (test_filter.h) pins the base
  `Effect::needs_full_frame()` default.

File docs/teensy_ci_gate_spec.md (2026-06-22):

# Design Spec: Teensy 4 CI Gate — Build, Warning Hygiene, Image Size & Memory Layout

**Status:** Phase-0 scaffold + toolchain spike done. Landed & self-tested (report-only):
`platformio.ini` + the `tools/teensy_pre.py` sketch-placement hook, the post-build gate
(`tools/teensy_gate.py` + `tools/teensy_gate_extra.py`), budgets (`tools/teensy_budgets.json`), the
warning ratchet (`tools/teensy_warnings.py` + baseline), the host self-tests
(`tools/teensy_gate_tests/`, green), the `teensy-gate-tests` CI job, the `just teensy-size` recipe,
and the Teensy-4.0 doc reconciliation (§14.5).

**Phase-0 spike results (2026-06) — see §16:** the toolchain question is resolved favourably
(branch 1, exact bench parity): `platform = teensy@5.0.0` natively delivers Teensyduino 1.59.0 +
arm-none-eabi-gcc 11.3.1, `platformio==6.1.19`, `FastLED@3.10.3`. Two config corrections the real
build forced: (a) the Teensy core default `-std=gnu++17` must be `build_unflags`'d so the engine's
C++20 compiles; (b) PlatformIO's sketch discovery globs `$PROJECT_SRC_DIR/*.ino` and ignores
`build_src_filter`, so the spec's filter-only plan (§5/§6) can't place the `.ino` — a pre-script
selects it instead. The build now compiles `core/*.cpp` + the converted sketch cleanly.

**The gate earned its keep, then went green (2026-06).** The first headless device build surfaced
**real device-only breakage** invisible to the WASM/native CI; all of it is now FIXED (§16):
Arduino `TWO_PI` macro collisions (renamed to `kTwoPi` in `effects/{Flyby,Liquid2D,Raymarch}.h`),
the wrong FastLED pin (3.10.3 → the bench's **3.4.0**, which moved types into `namespace fl`),
`effects_legacy.h` `Pixel16`→`CRGB` explicit-conversion bit-rot, an ambiguous `pov` vs the `namespace
pov` (sketch var → `g_pov`), and a `color.h` include collision with FastLED's own `color.h`
(`hardware/` now uses `"core/color.h"`). **Result:** **Holosphere builds GREEN and PASSES the gate
end-to-end** on the real ELF (calibrated budgets + the real `_ZL18global_arena_block` mangled arena
symbol). **Phantasm compiles + links but OVERFLOWS RAM1 by ~243 KB** (all effects → ~381 KB ITCM +
~380 KB DTCM ≫ 512 KB) — the gate correctly fails it; shrinking it (-Os / FLASHMEM / fewer effects /
smaller arena) is owner-scope (§4.1 relief valve). The warning baseline is captured (1 first-party
warning — 55 `HS_CHECK` sites dedupe to one). Remaining: enable the `teensy-size` CI job
(`vars.TEENSY_GATE_ENABLED`) once Phantasm fits.
**Scope:** Add an automated gate that compiles the Teensy 4 firmware images, then validates
build success, warning hygiene, image size, and memory-region layout against checked-in budgets.
**Out of scope:** On-device flashing/running, hardware-in-the-loop tests, the WASM/native-test
paths (already covered by `ci.yml`).

---

## 1. Problem statement

The project has three build targets sharing one engine: the **WASM** simulator, the **native
unit suite**, and the **Teensy firmware** (`targets/Holosphere/Holosphere.ino`,
`targets/Phantasm/Phantasm.ino`). The first two are covered exhaustively by
`.github/workflows/ci.yml` (sharded Clang tests, ASan/UBSan, Windows, WASM build + runtime smoke
+ install provenance). **The firmware path is built nowhere automated** — it compiles only on a
developer machine through Visual Micro (VMicro).

Consequences of the gap:

- **Device-only code is uncompiled in CI.** Everything behind `#ifdef ARDUINO` / `CORE_TEENSY`
  — the eDMA register programming in `hardware/dma_led.h`, `pov_single.h`, `pov_segmented.h`,
  `IntervalTimer` ISR wiring, `DMAMEM`/`FLASHMEM` placement — can break without any signal until
  a human opens VMicro. `docs/device_host_divergence_ledger.md` row 4 records this directly:
  *"the bare DMA/register writes are device-only by nature and not host-reachable."*
- **No size or memory-layout signal.** The two framebuffers (`MAX_W*MAX_H` = 288×144 ×
  `sizeof(Pixel16)` = 6 B = **243 KiB each**; 486 KiB together) live in `DMAMEM` (OCRAM/RAM2,
  512 KiB total), the **335 KB arena lives in DTCM/RAM1** (`global_arena_block`, no `DMAMEM` — it
  is the largest single RAM1 object, [memory.cpp:43-53](../core/memory.cpp)), and the 90 KB
  reaction-graph table lives in flash. Both buffers are fixed at `MAX_W*MAX_H` for **both**
  targets regardless of virtual resolution, so OCRAM is genuinely tight (486 KiB of 512 KiB). A
  change that pushes any region over budget — or silently relocates a large buffer from flash to
  RAM, or grows the arena and squeezes the DTCM stack — is invisible until it either fails to link
  on-device or crashes at runtime where *"there is no debugger attached and no console to read"*
  (README §2).
- **No warning hygiene baseline.** arm-none-eabi-gcc with `-Wall -Wextra` surfaces warnings the
  Clang/Emscripten builds do not. Today nothing watches them.

This spec designs a **compile + link + measure** gate (no on-device execution) that closes the
compile/link/size blind spot, run headlessly in CI and reproducible locally.

---

## 2. Goals & non-goals

### Goals
1. Build both Teensy 4 firmware images headlessly, deterministically, version-pinned.
2. Fail CI on any **compile or link error** in device-only code paths.
3. Enforce **warning hygiene** (no *new* warnings, via a committed baseline ratchet — §7.2).
4. Enforce **image size** budgets per memory region (FLASH, RAM1/ITCM+DTCM, RAM2/OCRAM).
5. Validate **memory layout** invariants beyond raw totals — e.g. the framebuffers stay in
   OCRAM, the reaction-graph table stays in flash, the DTCM stack headroom is preserved.
6. Be **reproducible locally** with one command, so a developer who uses VMicro day-to-day can
   pre-flight the gate before pushing.
7. **Coexist with VMicro** — VMicro remains the edit/flash/debug tool; this gate never owns that
   workflow and the two must not fight over the working tree.

### Non-goals
- Replacing VMicro as the local development or upload path.
- Running effects on real hardware (no runner has a Teensy; that stays manual — README §11,
  memory `project_no_device_build_in_ci`).
- Re-validating sim≠device numeric divergence — that is the host device-value tests' job
  (`h_offset_renorm_check`, `fastmath_clamp_check`, the divergence ledger). This gate is about
  *does it build for the device and fit*, not *does it compute the same pixels*.

---

## 3. Why PlatformIO

The firmware today builds via VMicro, a Visual Studio GUI front-end over the Arduino/Teensyduino
toolchain. VMicro is excellent for interactive edit/flash/debug but is a poor CI citizen: it is
Windows + Visual Studio bound, GUI-oriented, and its project state (`__vm/`, `*.vcxproj`) is
machine-local and already `.gitignore`d.

Candidate headless build drivers:

| Option | Verdict |
|---|---|
| **PlatformIO** (`platform = teensy`, `framework = arduino`) | **Chosen.** Pure CLI, cross-platform, Linux-runner friendly, declarative `platformio.ini`, exact version pinning of platform/framework/toolchain/libs, built-in per-region size report, post-build hook API (`extra_scripts`) for custom size/layout parsing, first-class GitHub Actions support, trivial local reproduction (`pio run`). |
| **arduino-cli + teensy** | Viable but heavier to pin reproducibly; Teensy support via the third-party board manager URL is less ergonomic to cache; weaker hooks for size parsing. |
| **VMicro headless / MSBuild** | Ties CI to Windows + Visual Studio + a licensed/GUI tool; fragile and slow on runners. Rejected. |
| **Bare Makefile over Teensyduino** | Maximum control, maximum maintenance; we'd reinvent dependency/version management PlatformIO already does. Rejected. |

PlatformIO uses the **same underlying toolchain** Teensyduino/VMicro use (`arm-none-eabi-gcc`,
the Teensy core, `teensy_size`), so a green PlatformIO build is strong evidence the VMicro build
is also healthy — without claiming bit-identical artifacts.

---

## 4. Coexistence with VMicro

The two systems live side by side, each owning a different job:

| Concern | VMicro (local) | PlatformIO (CI + local pre-flight) |
|---|---|---|
| Edit / IntelliSense / flash / debug | ✅ primary | ❌ |
| Headless build for CI | ❌ | ✅ |
| Size / layout / warning gate | ❌ | ✅ |
| Project state on disk | `__vm/`, `*.vcxproj.user` (gitignored) | `.pio/` (add to `.gitignore`) |

Design rules to keep them from interfering:

- **Single source of truth for sources.** Both drivers compile the *same* `.ino` + `core/` +
  `hardware/` files. Neither generates or rewrites source. `platformio.ini` references the
  existing tree; it does not fork a copy.
- **No shared generated dirs.** Add `/.pio/` to `.gitignore` alongside the existing `__vm/`
  entry. PlatformIO never writes into `__vm/` and VMicro never writes into `.pio/`.
- **Include-path parity.** The committed VMicro project puts **`core/`, `effects/`, and
  `hardware/`** on the include path (vcxproj `IncludePath`, §4.1) — note `effects/`, which README
  §11's "`../../core;../../hardware`" omits. `platformio.ini` reproduces all three via
  `build_flags = -I core -I effects -I hardware`, so a file that compiles under one resolves the
  same headers under the other.
- **Library parity.** Both depend on `FastLED` (+ `SPI`, bundled with the core). PlatformIO
  pins `FastLED` in `lib_deps`; the pinned version should match what the developer has installed
  for VMicro to avoid "builds in CI, not locally" surprises (documented, not enforced).
- **Build-option parity (most consequential — flash size hinges on it).** VMicro bakes in Teensy
  "menu" selections that PlatformIO otherwise sets from its *own* defaults; the CI size numbers are
  only comparable to the flashed image if these match. **These have now been captured from the
  committed VMicro project** — see §4.1; `platformio.ini` must pin every row of that table.

### 4.1 Captured VMicro configuration (source of truth for parity)

Read from the committed Holosphere VMicro project — `targets/Holosphere/Holosphere.vcxproj`
(`UserProperties`), `__vm/Compile.vmps.xml` / `Configuration.Release.vmps.xml`, and
`__vm/.Holosphere.vsarduino.h`. This is the authoritative set the size gate must reproduce:

| Option | VMicro value | Evidence | PlatformIO encoding |
|---|---|---|---|
| Board | **Teensy 4.0** (`teensy40`, `Platform=teensy4`) | `.vsarduino.h` line 9; vmps `Platform` | `board = teensy40` |
| Core / Teensyduino | **1.59.0** (`TEENSYDUINO=159`) | vcxproj include path `.../avr/1.59.0/...`; vmps | pinned via `platform = teensy@<ver mapping to TD 1.59>` |
| GCC toolchain | **arm-none-eabi-gcc 11.3.1** | vcxproj `RemoteCppCompileToolExe` `.../teensy-compile/11.3.1/...` | comes with the pinned platform — verify it resolves to 11.3.1 |
| **Optimization** | **`-O3` ("Fastest", no LTO)** — owner-confirmed (`o3std`) | vcxproj `custom_teensy40_opt="o3std"` (the explicit override; last-build state still showed the `o2std`/`-O2` default) | `build_unflags = <PIO/Teensy default -O*>` **+** `build_flags = -O3`; no LTO |
| CPU speed | **600 MHz** (`F_CPU=600000000`) — board default | vcxproj `PreprocessorDefinitions` `F_CPU=600000000` | `board_build.f_cpu = 600000000L` |
| USB type | **Serial** (`USB_SERIAL`) — board default, no override | vcxproj `PreprocessorDefinitions` `USB_SERIAL` | `-D USB_SERIAL` (Teensy default; pin it explicitly) |
| Keyboard layout | **US English** (`LAYOUT_US_ENGLISH`) — default | vcxproj `PreprocessorDefinitions` `LAYOUT_US_ENGLISH` | `-D LAYOUT_US_ENGLISH` |
| CPU/FPU flags | `-mcpu=cortex-m7 -mfloat-abi=hard -mfpu=fpv5-d16 -mthumb` (`v7e-m+dp/hard`) | vmps; include path `thumb/v7e-m+dp/hard` | set by `board = teensy40` (verify) |
| C++ dialect | **`gnu++20`** (C: `gnu11`) | vcxproj `CppLanguageStandard=gnu++20`, `CLanguageStandard=gnu11` | Teensy core default is `gnu++17` — may need `build_unflags=-std=gnu++17` + `build_flags=-std=gnu++20` |
| Exceptions / RTTI | **OFF** — `-fno-exceptions -fno-rtti` | vmps default **and** explicit user flag | confirm parity (matters for the `std::nothrow` OOM path in `Phantasm.ino`) |
| Extra user C++ flags | `-fno-threadsafe-statics -fno-unwind-tables -fno-asynchronous-unwind-tables -fno-use-cxa-atexit` | vcxproj `VM_ADDITIONAL_COMPILER_CPP_FLAGS` | add verbatim to `build_flags` — they shrink code and must match |
| Warning suppressions | **`-Wno-psabi -Wno-deprecated -Wno-attributes`** | vcxproj `VM_ADDITIONAL_COMPILER_CPP_FLAGS` | add to `build_flags`; feeds §7.2 (these are already-tolerated warnings) |
| Include dirs | **`core/`, `effects/`, `hardware/`** (+ sketch dir + repo root via `-I …/../../`) | vcxproj `IncludePath`; user flag `-I{build.source.path}/../../` | `-I core -I effects -I hardware` — **`effects/` is parity; the repo root (via `src_dir=.`) is the real requirement**, see §6 |
| Core/lib optimization | `OptimiseLibs=True`, `OptimiseCore=True` | vmps `Compile` attrs | PlatformIO optimizes core/libs with the env flags by default |
| Linker script / FlexRAM split | Teensy core's `.ld` (ITCM↔DTCM FlexRAM bank config) | from `board = teensy40` + core 1.59 | **automatic** (same core ⇒ same `.ld`); see note below — load-bearing for the DTCM/RAM1 budget |

**FlexRAM / linker-script parity (the mechanism behind the RAM1 budget matching).** The Teensy 4
RAM1 (512 KiB) is split between ITCM (code) and DTCM (data + stack) in **32 KiB FlexRAM banks** by
the Teensy core's linker script. Because both VMicro and PlatformIO build with the *same* core
(1.59.0), they get the *same* `.ld` and the *same* split rule — so DTCM size (hence arena + stack
headroom, §7.4 #1/#4) matches the flashed image without any extra pinning. Two consequences worth
naming: it is parity we get for free *only as long as the core pin holds* (a core bump can change
the `.ld`), and the split is **quantized to 32 KiB** — when ITCM crosses a bank boundary, DTCM-free
jumps by a whole 32 KiB step. That's fine for the gate (it still fails when `dtcm_free_min_bytes`
is breached), but explains why that floor can move in 32 KiB increments rather than smoothly.

**Two corrections this capture forces on earlier drafts:**

1. **Optimization is `-O3` ("Fastest", no LTO) — owner-confirmed.** The committed override
   `custom_teensy40_opt="o3std"` (`-O3`) is authoritative; the `o2std`/`-O2` seen in the last-build
   vmps state was the stale default, and the earlier `-Os` recollection did not hold (no project
   file selects `osstd`). `-O3` is the **largest** image of the three (`-Os < -O2 < -O3`), so:
   - Calibrate `flash_max_bytes` (§8) against the **-O3** build, and
   - CI must `build_unflags` PlatformIO's Teensy default `-O*` and force `-O3` (no LTO) — the PIO
     default is unlikely to be `-O3`, so without this the gate would measure a *smaller* image than
     the bench flashes.
   - **Relief valve:** if Phase-0 calibration shows the `-O3` image doesn't fit (flash or OCRAM),
     dropping the bench to `-Os` is the obvious shrink — but that's an owner build-config change,
     mirrored in `platformio.ini`, not something the gate decides. For now the gate targets `-O3`.
2. **The repo root must be on the include path; `effects/` is kept for VMicro parity.** Correction
   to earlier drafts: the effect headers are *not* included by bare name — `core/effects.h` pulls
   them PATH-PREFIXED (`#include "effects/BZReactionDiffusion.h"`), and those headers in turn include
   `core/...` and `effects/...` siblings the same way. Those path-prefixed includes resolve from the
   **repo root**, which PlatformIO puts on the include path automatically via `src_dir = .` — *that*
   is the load-bearing requirement, not `-I effects`. `-I core` / `-I hardware` are still needed for
   the BARE `effects.h` / `effects_legacy.h` / `pov_single.h` includes in the `.ino`. `-I effects` is
   retained to mirror VMicro's `../../effects` (vcxproj line 67) and guard a future bare-name include,
   but the current tree does not require it (§6). README §11's include-dir hint is updated to add
   `../../effects` for VMicro parity regardless.

> **Scope of the capture.** Only **Holosphere** has a committed VMicro/VS project; **Phantasm has
> none** to read. The table above is therefore Holosphere's actual config; Phantasm is assumed to
> use the **same** board/optimization/USB/toolchain (same author, same bench) and only adds
> `-D USE_DMA_LEDS`. Phase 0 must confirm that assumption with the owner before locking Phantasm's
> flash budget — it is the one remaining unread option set.

---

## 5. Source layout mapping

PlatformIO's default convention is `src/` with `.cpp`. This repo keeps per-target `.ino` entry
points under `targets/`. We map without moving files using per-environment `src_dir`/`src_filter`
(or `build_src_dir`):

Both targets are **Teensy 4.0** (project-owner confirmed; the 2 MB flash figure follows from
that — see the board note below). They differ in output path and design resolution, not board.
**The gate builds whatever each `.ino` actually commits** — Holosphere's design resolution is
96×20 (README §1) but `Holosphere.ino` is currently set to 288×144 top to bottom (a WIP state);
Phantasm is 288×144 and selects the DMA HD107S path (`#define USE_DMA_LEDS`). The size budgets key
on the committed image, not the design figure.

> **Phantasm is one image shared across four boards.** `Phantasm.ino` reads a hardware ID at boot
> ([lines 11-23](../targets/Phantasm/Phantasm.ino)) and the *same* binary runs on all four
> ID-selected Teensys (a 4-node segmented display, 72 LEDs each). For this compile/size gate that
> is a single image to build and budget; the "288×144" is the assembled virtual display, not one
> board's output.

> **Static footprints are *mostly* shared, but RAM2 is not identical.** The framebuffers
> ([memory.cpp:139-141](../core/memory.cpp)) and the arena are sized by compile-time constants
> (`MAX_W=288`, `MAX_H=144`, `GLOBAL_ARENA_SIZE=335 KB`), **not** by virtual resolution — so both
> allocate the same two 243 KiB buffers in OCRAM and the same 335 KB arena in DTCM. But Phantasm's
> `USE_DMA_LEDS` path adds an OCRAM consumer Holosphere lacks: the double-buffered
> `DMAMEM DMALEDController` eDMA TX frame buffers ([pov_segmented.h:802-810](../hardware/pov_segmented.h)),
> where Holosphere's FastLED path uses a non-`DMAMEM` `CRGB leds_[]`. So the targets diverge in
> **flash** (different effects + USB/driver code) **and** in **RAM2/OCRAM** (Phantasm's DMA TX
> buffers) — which, given OCRAM's structural tightness (§8), means **Phantasm needs its own RAM2
> ceiling**, not a shared one. They do share the RAM1/DTCM (arena-dominated) footprint.

```
targets/
├── Holosphere/Holosphere.ino   ← env:holosphere  (board = teensy40; committed 288×144, design 96×20)
├── Phantasm/Phantasm.ino       ← env:phantasm    (board = teensy40, 288×144, USE_DMA_LEDS, 4 boards)
└── wasm/…                       ← untouched (CMake/Emscripten)
core/        memory.cpp, reaction_graph.cpp, *.h   ← compiled into both (lib or extra source)
hardware/    *.h                                    ← header-only, on include path
```

Key decisions:

- **Keep `.ino`, don't convert to `.cpp`.** PlatformIO compiles `.ino` (it runs the same
  prototype-injection preprocessing Arduino does). Converting to `.cpp` would diverge from the
  VMicro source of truth and risk auto-prototype differences. The `.ino` stays canonical.
- **`core/memory.cpp` and `core/reaction_graph.cpp` are real translation units** (the WASM build
  lists them explicitly in `CMakeLists.txt`). They must be added to the firmware build's source
  set — via `build_src_filter` including `core/*.cpp`, or by treating `core/` as a private
  library. The rest of `core/` and all of `hardware/` are header-only and reached via `-I`.
- **`effects_legacy.h` is in scope here even though it's excluded from code review.**
  `Holosphere.ino` includes it, so the firmware image must compile it. (The review-scope
  exclusion in `prompts/analysis.txt` is about *quality grading*, not *buildability*.)
- **Same board, different flags.** Both envs set `board = teensy40`. Phantasm adds
  `build_flags += -D USE_DMA_LEDS` to mirror the `#define USE_DMA_LEDS` the `.ino` already sets
  (keep the `#define` in the `.ino` as the source of truth; the env flag is only needed if a
  target ever relies on it being set before the first include). The two builds share the same
  board and RAM1 footprint but differ in flash *and* in RAM2 (Phantasm's DMA TX buffers, above) —
  so the budgets (§8) share RAM1 but give Phantasm its own flash and RAM2 ceilings.

> **Board note — confirmed Teensy 4.0, committed docs are stale (must reconcile, not "later").**
> The board pin is the single load-bearing assumption of the flash gate: T4.0 flash is **2 MB**,
> T4.1 is **8 MB**, so a wrong board makes `flash_max_bytes` meaningless and could false-fail a
> valid image on day one. The project owner has **confirmed both targets are Teensy 4.0** (there is
> no 4.1), so the gate pins `board = teensy40` and budgets flash against 2 MB. But `Phantasm.ino`'s
> header ([line 7](../targets/Phantasm/Phantasm.ino)) and README §1 still say *4× Teensy 4.1* —
> those committed lines are now **confirmed stale** and reconciling them to 4.0 is a **prerequisite
> of Phase 0/1**, not optional tidy-up, precisely because the budget depends on the board being
> unambiguous in the tree. Separately, `Holosphere.ino` is committed at 288×144 (header *and* body)
> while its design resolution is 96×20 — the gate budgets the committed image, and the resolution
> reconciliation is a parallel cleanup (§14 decision 5).

---

## 6. `platformio.ini` design (illustrative, not final)

```ini
[platformio]
src_dir = .                           # repo root — sources live in core/ and targets/, no src/
# Keep PlatformIO's tree out of the repo root; gitignored.
# Sources are referenced in place — no files move.

[env]
platform = teensy@<pinned>            # pin to the build giving Teensy core 1.59.0 / arm-gcc 11.3.1 (§4.1)
framework = arduino
board_build.f_cpu = 600000000L        # 600 MHz (§4.1)
build_cache_dir = .pio/build_cache    # object cache (mirrors ci.yml's ccache) — gitignored, CI-cached (§10)
lib_ldf_mode = chain                  # constrain the Library Dependency Finder; confirm scope in Phase-0 spike (§6)
build_unflags = -Os                   # drop PlatformIO/Teensy default so the -O3 below wins (§4.1)
build_flags =
    -O3                               # owner-confirmed "Fastest" (o3std), no LTO (§4.1)
    -I core
    -I effects                        # VMicro parity; repo-root (src_dir=.) resolves effects/*.h (§4.1)
    -I hardware
    -D USB_SERIAL                     # USB type (§4.1)
    -D LAYOUT_US_ENGLISH              # keyboard layout (§4.1)
    -std=gnu++20                      # match VMicro CppLanguageStandard (Teensy default is gnu++17)
    ; VMicro user flags, copied verbatim so code size matches the bench (§4.1):
    -fno-exceptions -fno-rtti -fno-threadsafe-statics
    -fno-unwind-tables -fno-asynchronous-unwind-tables -fno-use-cxa-atexit
    ; VMicro warning suppressions — these are already-tolerated; keep them so the §7.2
    ; baseline isn't polluted by warnings the bench build never shows:
    -Wno-psabi -Wno-deprecated -Wno-attributes
    -Wall -Wextra                     # warning hygiene (baseline ratchet, not -Werror — §7.2)
lib_deps =
    fastled/FastLED@<pinned>
# src_dir is the repo root, so the filter must START by excluding everything and
# then add back ONLY the wanted TUs — otherwise targets/wasm/, build*/ , .pio/,
# obj/, out/ etc. get swept in. Both targets compile the two real core TUs:
build_src_filter =
    -<*>
    +<core/memory.cpp>
    +<core/reaction_graph.cpp>

[env:holosphere]
board = teensy40                       # 96×20
build_src_filter = ${env.build_src_filter} +<targets/Holosphere/Holosphere.ino>

[env:phantasm]
board = teensy40                       # 288×144, DMA HD107S path
build_flags = ${env.build_flags} -D USE_DMA_LEDS
build_src_filter = ${env.build_src_filter} +<targets/Phantasm/Phantasm.ino>
```

> **Load-bearing mechanic — de-risk in Phase 0.** This is the one part most likely to misbehave on
> the first try, so it is **not** "just an implementation detail." `build_src_filter` resolves
> relative to a single `src_dir`; the repo has sources in both `core/` and `targets/<X>/` and no
> `src/`, which forces `src_dir = .` (repo root). At repo root the filter must default-exclude
> (`-<*>`) and add back only the exact wanted TUs, or it will pull in `targets/wasm/wasm.cpp`,
> the CMake `build*/` trees, `.pio/`, `obj/`, `out/`, and FastLED sources. Phase 0 (§13) must
> include a spike that confirms each env compiles *exactly* its `.ino` + the two `core/*.cpp` TUs
> and nothing else (verify via the build's compiled-source list), and pins down the precise
> exclude set. The spike must also: (a) confirm the option **name** for the pinned PlatformIO Core
> version — the key was `src_filter` in older PIO and `build_src_filter` in newer releases, use
> whichever the pin accepts; and (b) confirm the **Library Dependency Finder** (`lib_ldf_mode`)
> does not wander the repo root (`targets/wasm/`, `build*/`, `.pio/`) — with `src_dir = .` the LDF
> can scan far more than intended, a perf and surprise-dependency risk adjacent to the filter
> hazard. The design contract otherwise stands: **two named environments, one real device board,
> the existing sources in place, pinned everything.**

### Version pinning (reproducibility contract)
Mirror `ci.yml`'s discipline (it pins clang-18, emsdk 5.0.0 by commit SHA, ubuntu-24.04). Pin:
- `platform = teensy@…` — **pin by git URL + commit SHA, not a version tag.** `ci.yml` pins emsdk
  by commit SHA precisely because a tag is mutable/re-pointable; a `teensy@X.Y.Z` tag is the weaker
  bar the spec elsewhere criticizes. Use `platform = https://github.com/platformio/platform-teensy.git#<sha>`
  (or a vendored fork) so the toolchain can't shift under a retagged release.
- `framework-arduinoteensy` package version (via the platform pin),
- `fastled/FastLED@X.Y.Z` (pin to a tag at minimum; SHA if you want full parity with the bar above),
- the PlatformIO Core version itself (install a fixed `platformio==X.Y` in the CI step),
- the runner image (`ubuntu-24.04`, not `-latest`).

A toolchain bump is then a deliberate, reviewable one-line change — and because the size budgets
are toolchain-sensitive (a new GCC changes codegen size), the pin is what makes the size gate
meaningful frame-over-frame.

> **⚠ Phase-0 gating spike (do this FIRST — it's go/no-go, not a verification line item).** The
> whole "green PlatformIO ≈ healthy VMicro" argument assumes PlatformIO can actually deliver the
> **bench toolchain: Teensyduino 1.59.0 + arm-gcc 11.3.1** (§4.1). The upstream `platform-teensy`
> package has historically *lagged* Teensyduino releases, so there may be **no published platform
> version that yields exactly TD 1.59 / gcc 11.3.1.** Resolve this before anything downstream,
> because budgets and the warning baseline are toolchain-sensitive. Decision tree with a written
> fallback:
> 1. **A pinnable platform commit yields TD 1.59 / gcc 11.3.1** → pin it (above); done.
> 2. **It doesn't** → override the toolchain via `platform_packages` pointing at the
>    Teensyduino-provided `toolchain-gccarmnoneeabi` + framework (or vendor a platform fork) to
>    force 11.3.1.
> 3. **Neither is practical** → accept a *different but pinned* toolchain, and **recalibrate**
>    budgets + warning baseline against it — explicitly noting that CI then approximates (not
>    mirrors) the bench compiler. This is acceptable for a size/link gate but must be stated, not
>    silent.
>
> Everything else in this spec is downstream of this spike: if none of the three branches is
> acceptable, the *driver* (PlatformIO) is reconsidered, not just a number.

---

## 7. Validation dimensions

### 7.1 Build success
`pio run -e holosphere -e phantasm`. Any compile or link failure fails the job. This alone closes
the largest part of the gap: device-only `#ifdef ARDUINO` code now has a compiler pointed at it
on every push.

### 7.2 Warning hygiene — baseline ratchet *(decided)*
Policy: **baseline ratchet**, not hard `-Werror`. The tree is not yet known to be warning-clean
under arm-none-eabi-gcc, and a `-Werror` flip would either block landing the build gate or force a
large up-front cleanup. The ratchet lets the build gate land now while still preventing *new*
warnings.

- Compile with `-Wall -Wextra` (defer `-Wshadow`/`-Wconversion` — likely noisy; revisit once the
  baseline is clean).
- **Capture a committed baseline as an unordered, deduplicated set.** Store a fingerprint of the
  current first-party warning set (e.g. `tools/teensy_warning_baseline.txt`: normalized `warning:`
  lines with volatile bits — absolute paths, line numbers, column — stripped so the fingerprint is
  stable across unrelated edits). **The comparison must be set-based (sorted, de-duplicated), not a
  line-ordered diff:** PlatformIO builds in parallel (`-j`), so warning *emission order* is
  nondeterministic run-to-run — an ordered diff would flap green/red on identical inputs. The gate
  compares the build's warning *set* against the baseline *set* and **fails only on members not in
  the baseline**. A real fix that removes a baseline warning is fine; the gate flags *additions*.
- **Library noise excluded.** FastLED and the Teensy core emit their own warnings. The plan is
  `-isystem` for vendored/core includes so their warnings never enter the set — **but demoting the
  Teensy core to `-isystem` under PlatformIO is non-trivial (the core is added by the framework,
  not by us), so make "confirm the core/FastLED can actually be `-isystem`'d" a Phase-0 spike**, not
  an assumed capability. The first-party path filter (keep only `core/`, `effects/`, `hardware/`,
  `targets/` warnings) is an independent backstop, so the design is robust even if the `-isystem`
  demotion proves awkward.
- **The warning gate must run on a *clean* (cache-disabled) build — it cannot share the cached size
  build.** The object cache (§10, `build_cache_dir`) suppresses compiler invocation on a hit, so a
  cached TU emits **no** warnings: a warm build produces a *smaller* warning set than a cold one,
  and a new warning introduced in a **header** is invisible whenever the dependent TU is served from
  cache. Set-based comparison fixes emission *order*, not this. Resolution: the **size** build stays
  cached (objects don't change between warm runs), but the **warning** capture runs a separate
  build with the cache disabled (e.g. a dedicated env or `PLATFORMIO_BUILD_CACHE_DIR=` empty / a
  forced clean) so every first-party TU re-emits its warnings every run. Decouple the two; don't let
  the cache that makes the size job fast silently blind the warning ratchet. (If a full clean build
  is too slow, the documented fallback is scoping the ratchet to changed TUs — but then the
  header-introduced-warning blind spot must be stated, not hidden.)
- **`effects_legacy.h` warnings will be in the baseline.** It is review-excluded but in *build*
  scope (`Holosphere.ino` includes it, §5), so whatever it warns under arm-gcc lands in the
  committed first-party baseline. That's correct (the firmware does compile it); just don't be
  surprised to see review-excluded code in `teensy_warning_baseline.txt`.
- **Updating the baseline is a reviewed act.** A `--update-baseline` script regenerates the file;
  it lands in the same PR as the change that legitimately alters the warning set, so the diff is
  visible in review (same discipline as the LUT/reaction-graph provenance gates).
- **Phasing:** ship report-only for a PR or two to capture a stable baseline, then enforce
  (Phase 2, §13).

### 7.3 Image size
Teensy's post-build `teensy_size` (run automatically by the Teensy platform) prints per-region
usage, e.g.:

```
teensy_size: FLASH: code:NNNNN, data:NNNN, headers:NNNN   free for files: NNNNNN
teensy_size: RAM1: variables:NNNNN, code:NNNNN, padding:NNNNN   free for local variables: NNNNN
teensy_size: RAM2: variables:NNNNN   free for malloc/new: NNNNNN
```

- **RAM1** = ITCM (fast code) + DTCM (fast `.bss`/`.data` + stack). **The 335 KB arena
  (`global_arena_block`) lives here** — it is a plain static array with no `DMAMEM` qualifier
  ([memory.cpp:43-53](../core/memory.cpp)) and is the dominant RAM1 occupant. The stack also grows
  down within DTCM.
- **RAM2** = OCRAM: `DMAMEM` variables — the two 243 KiB framebuffers and the timeline event
  buffer — plus the heap (`malloc`/`new`: the `POVSegmented`/`POVDisplay` driver objects). The
  arena is **not** here, and is not heap-allocated.
- **FLASH** = code + `const`/`PROGMEM`/`FLASHMEM` data (incl. the 90 KB reaction-graph table) +
  headers.

The gate parses these and enforces a **budget per region per target** (§8). Thresholds carry
headroom — failing *before* 100% so there's room to flash and to grow the stack, not at the
linker's hard wall.

### 7.4 Memory layout
Raw totals miss structural regressions. Validate **invariants** by inspecting section/symbol
placement from the ELF. **Classify each symbol by its load address against the Teensy 4 memory
map, not by an `nm` type letter** — DTCM `.bss` and OCRAM `.dmabuffers` are *both* NOBITS, so `nm`
reports both as `b`/`B` and cannot tell a DTCM buffer from an OCRAM one (it would miss the exact
DMAMEM→DTCM regression invariant #2 targets). Use `arm-none-eabi-readelf -s`/`-S` (symbol →
section), or each symbol's address bucketed by region — ITCM `0x0000_0000`, FLASH `0x6000_0000`,
DTCM `0x2000_0000`, OCRAM `0x2020_0000` — cross-checked against the `.map`. `size -A` still gives
per-section totals; `nm` alone is insufficient for the placement checks below.

**Match symbols by their mangled / linkage names — the parser must not assume source spellings.**
`Effect::buffer_a` is a class static, so it appears mangled (`_ZN6Effect8buffer_aE`);
`global_arena_block` is `static` (internal linkage) and may show as a local symbol. The classifier
must either demangle (`arm-none-eabi-c++filt`, or `readelf`'s demangle) or match the mangled form
directly, and the §9.1 golden fixtures must contain **real `readelf -s` output with the actual
mangled strings** so the tests exercise the real matching, not a tidied alias. This is an easy spot
to be silently wrong (a name that never matches → the invariant never fires → false-green).

1. **Arena in DTCM/RAM1, and its size ≈ 335 KB (assert the magnitude, not just the section).**
   `global_arena_block` must stay in DTCM (`.bss`, no `DMAMEM`) **and** measure ~`GLOBAL_ARENA_SIZE`
   = 335 KB ([memory.h:33](../core/memory.h)). Pinning the *magnitude* matters: under
   `HS_TEST_BUILD` the same constant is **8 MB** ([memory.h:31](../core/memory.h)), so if that
   test-only macro ever leaked into the firmware build the arena would silently balloon 24× — a
   "still in DTCM" check passes, a "~335 KB ± tolerance" check catches it. It is the **largest RAM1
   object and the most likely RAM1-budget mover** — a change to `GLOBAL_ARENA_SIZE`, or accidentally
   tagging the block `DMAMEM` (which would shove 335 KB into already-tight OCRAM), shows up here too.
2. **Framebuffers in OCRAM, not DTCM.** `buffer_a`/`buffer_b` (the `DMAMEM Pixel[MAX_W*MAX_H]`
   arrays) must land in the OCRAM/`.dmabuffers` section. If a refactor drops the `DMAMEM`
   qualifier they'd silently move into DTCM and blow the fast-RAM/stack budget — a layout bug a
   size *total* might not catch but an *attribution* check will.
3. **Reaction-graph table in flash, not RAM.** The 90 KB `reaction_graph.cpp` table must be in a
   flash/`.rodata` section; a missing `const` qualifier would pull it into RAM and is an instant
   90 KB regression. Key the check on the **section** (flash/`.rodata`), *not* on a literal
   `PROGMEM` marker: on the Teensy 4's memory-mapped flash `PROGMEM` is essentially decorative —
   it's the `const` that keeps the table out of RAM ([reaction_graph.cpp:4](../core/reaction_graph.cpp)).
4. **DTCM stack headroom (link-time availability, not runtime depth).** Assert RAM1 "free for local
   variables" (= DTCM minus the arena and other `.bss`/`.data`) stays above a floor. This measures
   *how much room the linker left for the stack*, **not** actual runtime stack depth — it is not
   stack-overflow protection, it just guarantees the static allocations didn't crowd the stack space
   out. The stack grows down into this region at runtime. Mirrors the WASM build's stack-size
   vigilance (`-sSTACK_SIZE`, the debug 64 KB override note in `CMakeLists.txt`).
5. **(Optional) named-symbol size caps** for the largest known objects, so an unexpected balloon
   in a specific buffer is attributed, not just summed.

---

## 8. Budget / threshold model

A checked-in, reviewable budget file (e.g. `tools/teensy_budgets.json`) — analogous in spirit to
the committed LUT/reaction-graph provenance the existing CI guards:

Both targets are Teensy 4.0, so both share the same hard region sizes (2 MiB FLASH, 512 KiB RAM1
ITCM+DTCM, 512 KiB RAM2 OCRAM). The framebuffers and arena are sized by compile-time constants
identically for both (§5), so the two targets share their **RAM1/DTCM** footprint. They diverge in
**FLASH** (different effects + DMA vs FastLED path) and, *in principle*, in **RAM2/OCRAM** —
Phantasm's `USE_DMA_LEDS` path adds the `DMAMEM DMALEDController` eDMA TX buffers Holosphere lacks
(§5).

> **Right-sizing: the OCRAM *layout invariant* is the real value; a *separate numeric* RAM2 ceiling
> is a Phase-0 call, not an a-priori requirement.** The DMA TX delta is the double-buffered frame
> for ~72 LEDs/segment — order of a few hundred bytes against OCRAM's ~26 KiB margin. So the thing
> that actually protects OCRAM is the **`dma_tx_buffers_section: OCRAM` layout check** (a dropped
> `DMAMEM` there is a correctness bug regardless of bytes), not a second hand-maintained number.
> **Default to a single shared OCRAM ceiling + the layout invariant**, and only split into a
> separate, tighter Phantasm `ram2_max_bytes` if Phase-0's recorded as-built delta proves it earns
> the extra budget to maintain. The JSON below shows the *split* form for completeness; collapsing
> `ram2_max_bytes` to one shared value is the expected outcome.

```jsonc
{
  "holosphere": {
    "board": "teensy40",
    "flash_max_bytes":  1900000,   // < 2 MiB T4.0 flash, with headroom
    "ram1_max_bytes":   480000,    // DTCM dominated by the ~335 KB arena (+ stack, .bss) (of 512 KiB)
    "ram2_max_bytes":   510000,    // OCRAM: 2×243 KiB buffers = 497,664 B ALONE — see tightness note
    "dtcm_free_min_bytes": 16384,  // stack headroom floor (DTCM after arena/.bss)
    "layout": {
      "arena_section": "DTCM",
      "framebuffers_section": "OCRAM",
      "reaction_graph_section": "FLASH"
    }
  },
  "phantasm": {
    "board": "teensy40",
    "flash_max_bytes":  1900000,   // calibrate separately — different effect set + DMA/USB code
    "ram1_max_bytes":   480000,    // shared with Holosphere (same arena/buffers)
    "ram2_max_bytes":   "<tighter>", // OCRAM: framebuffers + the DMALEDController TX buffers — its own cap
    "dtcm_free_min_bytes": 16384,
    "layout": {
      "arena_section": "DTCM",
      "framebuffers_section": "OCRAM",
      "dma_tx_buffers_section": "OCRAM",   // DMALEDController must stay DMA-reachable (OCRAM), see §5
      "reaction_graph_section": "FLASH"
    }
  }
}
```

Two callouts the calibration in Phase 0 must respect:

- **The arena dominates RAM1.** `ram1_max_bytes` and `dtcm_free_min_bytes` are governed by
  `GLOBAL_ARENA_SIZE` (335 KB) plus the stack; that constant is the most likely thing to move the
  RAM1 budget. The layout check (§7.4 #1) pins it in DTCM *and* near 335 KB. Note `dtcm_free_min_bytes`
  can step by a whole **32 KiB** when ITCM crosses a FlexRAM bank boundary (§4.1 FlexRAM note) — a
  jump in the floor, not smooth drift; the gate still fires correctly, it's just lumpy.
- **OCRAM headroom is structurally small, not a free parameter.** The two static framebuffers are
  **497,664 B of OCRAM's 524,288 B** — leaving only ~**26 KiB** for the timeline event buffer
  (`global_timeline_events`, `TIMELINE_MAX_EVENTS=64` — small, ~a few KiB) and all `new`/`malloc`
  (the driver objects; Phantasm's `DMALEDController` TX buffers also sit here). The known consumers
  are small, so the **current image very likely fits today** — but the margin is thin enough that
  the gate's value is real. A placeholder like `ram2_max_bytes: 500000` is *barely above the buffers
  alone* — that is not "headroom." **Phase 0 must record the as-built OCRAM-free number** so the
  framing is explicit: if Phantasm is already near the wall, the gate's first act is *surfacing
  existing tightness*, not just *preventing future* growth. Either way the buffers are fixed at
  `MAX_W*MAX_H`, so the only give is the heap.

**Enforcement: absolute ceilings only** *(decided)*. The gate hard-fails if any region exceeds its
cap — catching "won't fit / no room to flash" and the layout invariants (§7.4). A per-build
**regression-delta** check (fail on growth beyond a tolerance vs a committed size baseline) was
*considered and deferred*: it adds a second baseline to maintain and would make routine effect
work churn the baseline file. Ceilings with deliberate headroom give the needed protection without
that overhead; the delta gate can be revisited later if size creep proves to be a real problem.

**Raising a ceiling is a reviewed, one-line edit** to `tools/teensy_budgets.json`, landed in the
*same* PR as the change that needs it — the symmetric escape hatch to the warning baseline's
`--update-baseline` (§7.2). A budget bump is therefore visible in review (you can see the headroom
shrink) rather than silent; provide a small `--show`/`--update` helper that re-reads the current
build and prints the would-be values to make the edit mechanical.

Headroom numbers above are placeholders — calibrate from the first real build's `teensy_size`
output before enabling enforcement.

---

## 9. Measurement mechanism

A small **PlatformIO `extra_scripts` post-build hook** (Python) is the cleanest integration point:

1. After link, locate the ELF (`$BUILD_DIR/firmware.elf`).
2. Run `teensy_size` (or `arm-none-eabi-size -A`) and parse region totals.
3. Run `arm-none-eabi-readelf -s -S` (and/or parse the `.map`) and classify the framebuffer,
   arena, DMA-TX, and reaction-graph symbols **by load address against the Teensy 4 memory map**
   (§7.4) — DTCM/OCRAM are both NOBITS so `nm` type letters can't separate them. This is what makes
   the placement invariants (arena→DTCM, framebuffers/DMA-TX→OCRAM, table→FLASH) actually
   detectable.
4. Compare against `tools/teensy_budgets.json`; emit a clear pass/fail report.
5. **Fail the build on violation.** Attach the hook via
   `env.AddPostAction("$BUILD_DIR/${PROGNAME}.elf", check_fn)` and have `check_fn` call
   `sys.exit(1)` (or `raise`) on any violation — a post-action that merely prints does **not** fail
   `pio run`; the non-zero exit / exception is what propagates. Emit GitHub Actions annotations
   (`::error::…`) first so violations surface inline on the PR, matching `ci.yml` convention.

Keeping the parser in a versioned script (not inline YAML) means it is unit-testable and reused
verbatim by the local pre-flight command (§11). The toolchain binaries (`teensy_size`,
`arm-none-eabi-readelf`, `-size`) ship inside the pinned PlatformIO Teensy package, so no extra
install.

### 9.1 The gate must gate itself — negative/golden tests *(highest-value deliverable)*

A size/layout check that can never fail is **worse than none**: it renders green while covering
nothing, and a subtle address-bucket bug yields permanent false-green. So the parser and *every*
layout invariant ship with tests that prove each one **fails when it should** — this is a required
deliverable of Phase 0/1, not an optional nicety:

- **Golden fixtures.** Commit captured `arm-none-eabi-size -A` / `readelf -s -S` output from a known
  build under `tools/teensy_gate_tests/`, and assert the parser extracts the expected region totals
  and symbol→section classifications from them (no toolchain needed to run the parser tests).
- **Deliberately-broken cases — one per invariant, each must turn the check red:**
  - framebuffer fixture with `DMAMEM` dropped → symbol lands in DTCM → **framebuffers→OCRAM check
    must fail**;
  - reaction-graph fixture with `const` dropped → symbol in RAM → **table→FLASH check must fail**;
  - arena fixture at the 8 MB `HS_TEST_BUILD` size → **arena ~335 KB magnitude check must fail**
    (§7.4 #1);
  - an over-cap totals fixture → **each region ceiling must fail**.
- **Address-bucketing unit tests** for the Teensy 4 memory-map classifier (ITCM/FLASH/DTCM/OCRAM
  boundaries), since that logic is the load-bearing replacement for `nm` and the easiest place for a
  silent off-by-one to hide.

These run as ordinary host Python tests (fast, no ARM toolchain), so they can live in the existing
CI test job or a tiny dedicated step — independent of the slow PlatformIO build.

---

## 10. CI integration

A new job in `.github/workflows/ci.yml` (it already fans out tests/sanitizers/wasm/provenance;
this slots in alongside):

A **single job builds both envs** (no matrix) — they share one Teensy toolchain, so a matrix would
download it twice for marginal isolation. `pio run` builds the envs sequentially and reports per-env
size, and the gate script fails the step on the first env that violates a budget; this is the same
invocation the local recipe uses (§11):

```yaml
  teensy-size:
    name: Teensy 4 firmware (build + size + layout)
    runs-on: ubuntu-24.04
    # Skip the heavy toolchain restore on changes that can't affect the firmware image
    # (docs, the WASM/daydream side, the native tests). Scope to what the image is built
    # from. NOTE: path filters only apply to pull_request/push events; the required-check
    # below must tolerate "skipped" as success on out-of-scope PRs (see Notes).
    # (Apply via the workflow-level on.<event>.paths, or a paths-filter step.)
    #   paths: [ core/**, effects/**, hardware/**, targets/**, platformio.ini,
    #            tools/teensy_*, .github/workflows/ci.yml ]
    steps:
      - uses: actions/checkout@v4
      - uses: actions/setup-python@v5        # PlatformIO is a Python package
        with: { python-version: '3.x' }
      - name: Cache PlatformIO toolchain
        uses: actions/cache@v4
        with:
          path: ~/.platformio
          # Target-agnostic (toolchain doesn't vary by env, so both share one entry),
          # but DO include everything that changes ~/.platformio contents: the pinned
          # platform version, the FastLED pin, and the PlatformIO Core version — else a
          # dependency bump silently restores a stale cache.
          key: pio-teensy-<platform-ver>-<fastled-ver>-<pio-core-ver>
          # Optional: hashFiles('platformio.ini') to auto-rotate on any pin change.
      - name: Cache build objects               # mirrors ci.yml's ccache discipline
        uses: actions/cache@v4
        with:
          # build_cache_dir from platformio.ini — without this the 7,685-line
          # reaction_graph.cpp + FastLED recompile from scratch on every run, ×2 envs.
          path: .pio/build_cache
          # github.sha makes each commit write a fresh entry, restoring from the newest
          # prefix match — standard, but it does churn the cache (Actions evicts at the
          # 10 GB repo budget, LRU). Fine for object caches; just don't be surprised.
          key: pio-objs-<platform-ver>-${{ hashFiles('platformio.ini') }}-${{ github.sha }}
          restore-keys: pio-objs-<platform-ver>-
      - name: Install pinned PlatformIO
        run: pip install 'platformio==<pinned>'
      - name: Build + size + layout gate (both targets)
        run: pio run -e holosphere -e phantasm   # extra_script enforces per-env budgets, sets exit code
      - name: Upload firmware artifacts            # optional: .hex/.elf for inspection
        uses: actions/upload-artifact@v4
        with: { name: firmware, path: .pio/build/*/firmware.* }
```

Notes:
- **No hardware, no upload** — build + link + measure only. Runs on a stock Linux runner.
- **Required status check, flipped at Phase 1.** "Fail CI" only blocks merges if `teensy-size` is a
  *required* status check in branch protection. The phasing maps directly: Phase 0 runs it
  report-only (not required), Phase 1 makes it required once budgets are calibrated. When using
  `paths:` scoping, make the required check tolerate a *skipped* run as success (a path-filtered job
  that doesn't run must not block out-of-scope PRs) — e.g. a always-passing companion job, or
  `dorny/paths-filter` gating the heavy step rather than the whole job.
- **Two caches, like `ci.yml`.** `~/.platformio` (toolchain/packages) *and* `build_cache_dir`
  (objects). Without the object cache the big TU + FastLED rebuild cold every run; with it, only
  changed TUs recompile — the same reason `ci.yml` runs ccache.
- **One job, both envs.** Cold-cache cost is one toolchain download, not two. If per-target
  *independent* failure isolation later proves worth the extra runner, fall back to a matrix — but
  keep the cache key target-agnostic (above) so the warm-cache case still shares one entry.
- **Cache `~/.platformio`** (the toolchain + framework packages) keyed on the pinned platform
  version (target-agnostic), mirroring the ccache/emsdk caching already in `ci.yml`. First run
  downloads the Teensy toolchain (~hundreds of MB); subsequent runs restore it.
- This job is **additive** — it does not touch the existing tests/wasm jobs, and PlatformIO needs
  no `EMSDK`, so it composes cleanly with the memory note `project_no_device_build_in_ci` (which
  this gate partially supersedes for *compile/link/size*, while on-device *execution* stays
  manual).

---

## 11. Local parity (for a VMicro developer)

A developer who flashes via VMicro should be able to run the identical gate before pushing. Add a
`justfile` recipe (the repo already routes tasks through `just`):

```
# Build the Teensy firmware images and enforce size/layout budgets (CI parity).
teensy-size:
    pio run -e holosphere -e phantasm
```

`pio` is the only new prerequisite (`pip install platformio`); the Teensy toolchain auto-installs
on first `pio run`. This gives a one-command local pre-flight without disturbing the VMicro project.
The contract is **same pass/fail under the headroom'd ceilings**, *not* identical bytes: the dev
runs PIO on Windows while CI runs `ubuntu-24.04`, and arm-gcc — though largely host-deterministic —
can shift a few bytes via `__FILE__`/path-length or any build-timestamp injection. Same honesty as
the VMicro≠PIO note (§4): the gate asserts *fit*, not *bit-identity*. Document the recipe in README
§11 alongside the existing firmware build instructions.

---

## 12. Failure modes & reporting

| Failure | Signal | Example cause |
|---|---|---|
| Compile error in device path | `pio run` non-zero, compiler diagnostic | broke `#ifdef ARDUINO` code, missing header on `-I` path |
| Link error | linker diagnostic | undefined symbol only referenced on device, region overflow at hard wall |
| New warning | `::error::` from warning gate | baseline-ratchet trip (warning not in the committed baseline) |
| Region over budget | `::error::` from size parser, region + bytes + cap | added a large effect, dropped `FLASHMEM` |
| Layout invariant violated | `::error::` naming the symbol + wrong section | dropped `DMAMEM`/`const`, table moved to RAM |

All violations use the `::error::` annotation convention already established across `ci.yml` so
they render inline on the PR.

---

## 13. Rollout plan (phased)

1. **Phase 0 — spikes + land `platformio.ini` + the post-build script, report-only.** Build both
   targets in CI; print sizes/warnings; **do not fail** on thresholds yet (not a required check
   yet). Phase 0 must resolve the prerequisites that make the numbers meaningful:
   - **(0) FIRST: the toolchain go/no-go spike (§6).** Can PlatformIO deliver TD 1.59 / arm-gcc
     11.3.1, or which fallback (platform_packages override / fork / accept-and-recalibrate)? Settle
     this before any calibration — everything below is toolchain-sensitive, and a no-go could change
     the driver, not just a number.
   - (a) the `build_src_filter` spike (§6) confirming each env compiles exactly its `.ino` + the two
     `core/*.cpp`, **and** the `lib_ldf_mode` scope check (§6);
   - (b) **build-option parity** (§4.1) — already captured (optimization `-O3`, `f_cpu`, USB, layout,
     gnu++20, the `-fno-*`/`-Wno-*` flags); confirm they reproduce VMicro's image, and confirm the
     **`-isystem` demotion** of FastLED/the Teensy core actually works (§7.2);
   - (c) reconcile the stale "Teensy 4.1" references to 4.0 so the board/flash budget is unambiguous
     in the tree (§5 board note);
   - (d) **record the as-built per-region numbers** — especially OCRAM-free (§8) — so the
     regression-prevention-vs-existing-tightness framing is explicit;
   - (e) write the **negative/golden parser tests** (§9.1) so every invariant is proven to fail.

   Then calibrate real budgets (incl. Phantasm's separate RAM2 cap) and capture the initial warning
   baseline (as an unordered set, §7.2). (One or two PRs.)
2. **Phase 1 — enforce build + size (ceilings) + layout, and make the check required.** Set the
   calibrated ceilings and the layout invariants to hard-fail; with the negative tests (§9.1) green,
   flip `teensy-size` to a **required status check** (§10). Add the `just teensy-size` recipe and
   README docs (including the "Teensy 4.0 for both targets" fix, §14 decision 5).
3. **Phase 2 — enforce the warning baseline ratchet.** With the committed baseline in place
   (Phase 0) and `-isystem` excluding FastLED/core, fail on any first-party warning not in the
   baseline set.

Each phase is independently revertable and adds signal without destabilizing the existing green
CI. (A size regression-delta gate was considered and deferred — see §8 — so there is no Phase for
it.)

### 13.1 Acceptance criteria — "the gate is done when…"

1. Both envs (`holosphere`, `phantasm`) build **green** under the pinned toolchain, compiling
   exactly their `.ino` + the two `core/*.cpp` (filter spike confirmed, §6).
2. The build options reproduce the VMicro image: `-O3`, 600 MHz, `USB_SERIAL`, `gnu++20`, and the
   captured `-fno-*`/`-Wno-*` flags (§4.1).
3. All layout invariants — arena→DTCM ≈335 KB, framebuffers/DMA-TX→OCRAM, table→FLASH — are
   **demonstrably fail-then-pass** via the negative/golden fixtures (§9.1).
4. Per-region budgets are calibrated from a real `-O3` build, with the as-built OCRAM-free recorded
   (§8); Phantasm carries its own FLASH and RAM2 ceilings.
5. The warning baseline is captured (unordered set) and the ratchet fails on a synthetic new
   warning but not on reordering (§7.2).
6. `teensy-size` is a **required status check** that tolerates a path-skipped run as success (§10),
   and `just teensy-size` reproduces the CI *pass/fail* locally (§11).
7. **Wall-clock budget met.** Warm-cache run (toolchain + objects restored) completes under a stated
   target (e.g. **< ~3 min**); cold run (toolchain download + full `-O3` rebuild of the 7,685-line
   `reaction_graph.cpp` + FastLED × 2 envs) under a looser one. If warm runs blow the target, the
   object cache (§10) isn't engaging — investigate before flipping the check required.

---

## 14. Resolved decisions

All five prior open questions have been decided; the spec body reflects them.

1. **Targets — both.** Gate `Holosphere` *and* `Phantasm` (each currently committed at 288×144) —
   built in a single job (`pio run -e holosphere -e phantasm`), not a matrix, since both share one
   toolchain (§10). Both are **Teensy 4.0** (owner-confirmed). They share the RAM1/arena footprint
   and differ mainly in **flash** (different effects + DMA/USB code); the small OCRAM delta
   (Phantasm's DMA TX buffers) is guarded primarily by the `dma_tx_buffers_section: OCRAM` **layout
   invariant**, with a *separate* numeric RAM2 ceiling only if Phase-0's as-built delta warrants it
   (default: one shared OCRAM ceiling). Per-target **flash** ceilings stand. (§5, §8, §10)
2. **Warning policy — baseline ratchet.** Not hard `-Werror`. Capture a committed first-party
   warning baseline and fail only on new warnings, with `-isystem` excluding FastLED/the Teensy
   core. (§7.2, Phase 2 in §13)
3. **Size enforcement — absolute ceilings only.** Per-region caps with headroom; no
   regression-delta gate (considered and deferred to avoid a second baseline to churn). (§8)
4. **Workflow placement — inside `ci.yml`.** A new single `teensy-size` job (both envs in one
   `pio run`) alongside the existing tests/wasm/provenance jobs; shared triggers/concurrency, no
   separate workflow file. (§10)
5. **Fix the docs — agreed, and a Phase-0 prerequisite for the board pin.** The owner confirms
   **Teensy 4.0** for both (no 4.1). The stale "4× Teensy 4.1" lines in `Phantasm.ino:7` and
   README §1 must be reconciled to 4.0 **before** the flash budget is locked — the board fixes the
   flash ceiling (2 MB vs 8 MB), so an unambiguous tree is a prerequisite, not downstream tidy-up
   (§5 board note, Phase 0 in §13). The `Holosphere.ino` 288×144-vs-96×20 resolution mismatch is a
   parallel cleanup; the gate budgets the committed image regardless. The board lines **have now
   been reconciled to 4.0** (`Phantasm.ino:7`, README §1 and §11); the `Holosphere.ino` resolution
   mismatch remains the parallel cleanup.

---

## 15. Risks & mitigations

- **PlatformIO may not provide the bench toolchain (the one risk that can change the driver, not
  just a number).** `platform-teensy` has historically lagged Teensyduino, so TD 1.59 / arm-gcc
  11.3.1 may not be cleanly pinnable. Mitigate with the **first** Phase-0 spike (§6) and its written
  three-branch fallback (pin / `platform_packages` override / accept-and-recalibrate); a hard no-go
  reopens the tool choice (§3). Everything else is downstream of this.
- **Object cache can blind the warning ratchet.** A cached TU emits no warnings, so a warm build's
  warning set shrinks and header-introduced warnings hide. Mitigate by running the warning capture on
  a cache-disabled build, decoupled from the cached size build (§7.2).
- **Source-filter mechanic may leak unintended TUs (highest *build-config* risk).** With `src_dir = .`,
  `build_src_filter` must default-exclude and re-add only the wanted TUs or it sweeps in
  `targets/wasm/`, the CMake `build*/` trees, `.pio/`, etc. Mitigate with the Phase-0 spike (§6)
  that asserts each env compiles exactly its `.ino` + the two `core/*.cpp` and nothing else.
- **OCRAM is structurally tight (~26 KiB free after the two fixed framebuffers).** Not a tuning
  knob — the buffers are fixed at `MAX_W*MAX_H`. The known consumers (timeline events; Phantasm's
  small `DMALEDController` TX buffers) are sub-KiB, so the image very likely fits today; the value is
  the **layout invariant** keeping those buffers in OCRAM (`dma_tx_buffers_section: OCRAM`) plus the
  recorded as-built margin (§8). A future OCRAM consumer, or a bump to `MAX_W`/`MAX_H`, is the real
  risk the `ram2` ceiling + layout check must catch (§7.4 #2, §8).
- **Build-option drift between VMicro and PlatformIO defeats the size numbers.** If CI compiles at
  a different optimization level / USB type / `f_cpu` than the menu options used to flash, "fits in
  CI" ≠ "fits on the bench." Mitigate by pinning those options in `platformio.ini` to the captured
  VMicro selections (§4, Phase-0 deliverable).
- **Toolchain download weight / flakiness.** Mitigate with `~/.platformio` caching keyed on the
  pinned platform + FastLED + PIO-Core versions, target-agnostic so one entry serves both envs (§10).
- **arm-gcc surfaces warnings Clang/Emscripten don't.** Expected and *valuable* — that's coverage
  the other builds can't give. Phase the warning gate (§13) so it doesn't block landing the build
  gate.
- **Budgets become stale / bit-rot.** Keep the ceilings in a single reviewed JSON
  (`tools/teensy_budgets.json`), calibrated from real `teensy_size` output, not guesses; the
  warning baseline has its own reviewed `--update-baseline` path (§7.2).
- **VMicro/PlatformIO drift** (a file builds in one, not the other). Mitigate with strict
  include-path + library parity (§4) and the local `just teensy-size` pre-flight (§11). Note: the
  two will never be bit-identical artifacts; the contract is *both compile/link cleanly*, not
  *same bytes*.
- **`.ino` auto-prototype differences** between Arduino's and PlatformIO's preprocessors. Low risk
  (both implement the same Arduino convention); keeping `.ino` canonical rather than converting to
  `.cpp` avoids introducing a third behavior.
- **This gate does not run effects on-device.** It is a compile/link/size gate, not a behavioral
  one. On-device execution and the sim≠device numeric forks remain covered by manual flashing and
  the host device-value tests respectively (divergence ledger). Stated as a non-goal (§2) so the
  gate isn't mistaken for hardware validation.
```

---

## 16. Phase-0 spike log (2026-06)

The go/no-go toolchain spike (§6) was run with a real PlatformIO build. Outcome and the concrete
values now pinned:

**Toolchain — branch 1 (exact bench parity), no override needed.** `platform = teensy@5.0.0`
natively installs, for Teensy 4, the *same* PJRC toolchain Teensyduino/VMicro use:
`framework-arduinoteensy @ 1.159.0` (Teensyduino 1.59.0) and `toolchain-gccarmnoneeabi-teensy @
1.110301.0` (arm-none-eabi-gcc 11.3.1). The `toolchain-gccarmnoneeabi @ ~1.80201.0` (gcc 8.2.1) in
`platform.json` is for the older Teensy 3.x/LC boards, not Teensy 4 — an earlier draft misread it.
Pinned: `platform = teensy@5.0.0`, `platformio == 6.1.19`, `fastled/FastLED @ 3.10.3`. CI thus
*mirrors* the bench compiler. (Pin remains a version tag; a future SHA pin is optional hardening.)

**Two config corrections the build forced (now in `platformio.ini` / `tools/teensy_pre.py`):**
1. **`-std=gnu++17` must be unflagged.** The Teensy core appends `-std=gnu++17` after our flags, so
   `-std=gnu++20` lost and the engine's C++20 `concept` (memory.h) failed. Fixed via
   `build_unflags = ... -std=gnu++17`.
2. **Sketch discovery ignores `build_src_filter`.** PlatformIO finds the sketch only by globbing
   `$PROJECT_SRC_DIR/*.ino` (top level; `pioino.FindInoNodes`). With `src_dir = .` that finds no
   `.ino`, so `setup`/`loop` don't link. The spec's filter-only plan (§5/§6) cannot place the
   sketch. Fix: keep `src_dir = .` (so `core/*.cpp` build as project sources with full LDF include
   paths — FastLED, framework SPI) and override `FindInoNodes` per-env in `tools/teensy_pre.py`;
   `build_src_filter` then adds the converted `targets/<X>/<X>.ino.cpp`. Verified: `core/memory.cpp`,
   `core/reaction_graph.cpp`, and the converted sketch all compile.

**Headline finding (now resolved) — the gate surfaced real device-only bit-rot the WASM/native CI
cannot see.** Each was fixed; the device build is the first thing to compile this code under
`Arduino.h` + arm-gcc:
- **Arduino `TWO_PI` macro collision** — `effects/{Flyby,Liquid2D,Raymarch}.h` declared a local
  `constexpr float TWO_PI`, colliding with `wiring.h`'s `#define TWO_PI`. **Fixed:** renamed → `kTwoPi`.
- **Wrong FastLED pin** — I first pinned 3.10.3; the bench/Teensyduino 1.59 bundles **FastLED 3.4.0**,
  and 3.7+ moved `CHSVPalette16`/`HUE_RED`/`CEveryNMillis` and `CRGB`/`CHSV` into `namespace fl`.
  **Fixed:** pinned `FastLED@3.4.0` (§4.1 parity) — cleared a whole error class at once.
- **`effects_legacy.h` `Pixel16`→`CRGB`** (lines 25, 42, 100–112, 517, 743): `operator CRGB()` was made
  `explicit`, so the legacy effects no longer convert implicitly. **Fixed:** explicit `static_cast<CRGB>`.
- **Ambiguous `pov`** — the sketch var collided with the hardware `namespace pov` (pov_segment_map.h).
  **Fixed:** sketch var → `g_pov` in both `.ino`s.
- **`color.h` include collision** — FastLED ships its own `src/color.h`; the device `-I` order made
  `hardware/{dma_led,hd107s_frame}.h`'s bare `"color.h"` resolve to FastLED's (no `Pixel16`/LUTs),
  while host builds got the engine's. **Fixed:** those two now `#include "core/color.h"`.

**Result — Holosphere builds GREEN and the gate PASSES end-to-end on the real ELF.** Real calibrated
budgets (FLASH 154,620 / RAM1 459,072 free 65,216 / RAM2 518,272 free 6,016) and the **real** mangled
arena symbol `_ZL18global_arena_block` (the source spelling would never have matched — §7.4 vindicated).
The layout invariants are confirmed on real ELFs: arena→DTCM (343,040 B), framebuffers→OCRAM, and (on
a Phantasm ELF) reaction_graph→FLASH (`0x60003dc0`, 92,160 B). Parser quirks the real output exposed,
now handled: `teensy_size` prints to **stderr**, and `readelf` prints large sizes in **hex**. The
warning baseline is captured: **1** first-party warning (55 `HS_CHECK` call sites dedupe to one —
the set-based ratchet working as designed; and the object cache was observed blinding it, §7.2).

**Phantasm OVERFLOWS RAM1 by ~243 KB** (all effects via `HS_EFFECT_LIST` → ~381 KB ITCM + ~380 KB
DTCM). Its ELF was captured for symbol analysis by temporarily neutralizing `teensy_size`'s overflow
exit (reverted). RAM2 is ~518 KB / 524 KB for **both** targets — the structural OCRAM tightness the
spec predicted (§8). Shrinking Phantasm (-Os / FLASHMEM / fewer effects / smaller arena) is owner-scope.

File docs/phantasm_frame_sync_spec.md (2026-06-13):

# Phantasm Synchronization Architecture — Design Spec

*Status: IMPLEMENTED, and this document describes the implementation. The
protocol core lives in `hardware/pov_sync.h` (pure, host-tested — flywheel
timebase, symbol alphabet, edge mailbox, acceptance gate, beacon codec,
content tracker, emitter); the device shell is `hardware/pov_segmented.h`
(two ISRs, pixel packing, effect handoff); `targets/Phantasm/Phantasm.ino`
supplies the roster factory table; the §12 test plan is
`tests/test_pov_sync.h` (pure units plus a 4-board simulator with crystal
offsets, single-latch mask windows, EMI, symbol drops, missed epochs, and
mid-show reboots). Refinements that emerged during implementation are folded
into their sections: oversampled wake-ups (§4.1), the suspect-burst
demarcation guard (§5.3), the join grid and per-effect RNG reseed (§6.1,
§6.5), the beacon schedule (§6.4), and the effect-handoff protocol (§8.5).
One validation item remains open on hardware: measuring the worst-case
mask window M on the shipped LED path (§11.3).*

*Original status notes: this is a full-stack redesign of Phantasm's
cross-board timing, of which code-review finding #1 (the
frame-sync/`advance_display` desync) was one symptom at the frame layer.
Decisions taken: (1) spec the hybrid fully before implementing; (2)
**collapse to a single inter-board wire** — delete the shared column clock
and generate columns from a local, time-derived flywheel on every board;
(3) flip ownership = reconcile + self-describing sync pulses (A+C).*

*Review pass folded in (feasibility + correctness): the architecture is feasible
and the §4.5 drift math holds. Five findings were incorporated rather than left
implicit — (i) the symbol must be **count/burst-coded, not width-coded**, so the
very `FastLED.show()` masking the flywheel defeats can't corrupt the one wire all
layers ride (§5.2, §11.3); (ii) "extra flip is benign" is a **Layer-2-only**
statement — content `t` is flip-paced through the `buffer_free()` gate, so a
spurious flip offsets `t` until the next epoch (§8.4, §6.1); (iii) the §9
**master-dead** row is graceful precession, not a watchdog trap, now that
downstream owns its columns; (iv) the epoch **absolute index** is promoted toward
baseline (trap, don't assume index 0) (§6.3); (v) the non-preemption invariant is
a **downgrade** of the old design's same-vector guarantee (§8.2). Plus a best-possible
caveat: this is the best *open-loop* design; a rotor index would supersede it
(§13).*

*Reliability review folded in (this revision): (a) the ISR model is now
**single-writer** — the sync-wire ISR is a pure edge publisher and the flywheel
ISR the sole consumer/owner of all sync state, deleting the fragile
cross-peripheral equal-priority invariant outright (§8.2); (b) symbol
acceptance gets a **plausibility gate + ACQUIRE/LOCKED acquisition states**
(§5.3), closing the residual misclassification and spurious-flip holes; (c)
master **self-censors late emissions** and emits pin-first (§5.2), so emission
jitter — previously unbudgeted, and potentially ~170× the §4.5 drift budget —
cannot poison downstream phase; (d) the flywheel gains a **rebase rule and
64-bit position math** (§4.1), making cycle-counter wrap structurally
impossible rather than handled; (e) the epoch becomes a **deadline-scheduled
commit** (§6.1) — "atomic re-init" hid a multi-ms foreground operation with
per-board skew; (f) a mid-revolution **index beacon** (§6.4) lets a rebooted
board rejoin at the correct effect within ~2 s instead of trapping or
staying wrong for 120 s. Open decisions §11.2/3/4/5/7 are resolved. The sync
wire itself is assumed physically reliable — a hard, soldered line by
construction — so wire-dead is **accepted as out of scope**, not designed for.*

---

## 1. Goal

Make cross-board divergence on Phantasm **impossible to latch and fast to
self-correct at every layer** — column position, buffer-flip phase, *and*
displayed content (animation frame + effect) — without adding time-measurement
or branching to the per-column hot path, and **over a single wire** between
boards.

The insight driving the redesign: aligning the *display* (column + flip) is
necessary but **not sufficient** for a coherent image. Each board renders its
own copy of the effect in a free-running loop, so two boards can flip in perfect
time yet show different animation frames or even different effects. Coherence
requires a third, content layer that the previous design did not synchronize.

The second insight (this revision): once each board runs a disciplined local
flywheel, the continuous per-column clock wire is **redundant**. A flywheel that
derives column position from time and snaps to a boundary mark twice per
revolution holds sub-column alignment on its own (§4.5). So the two-wire design
collapses to one — the low-rate **sync-symbol wire** — and the column clock wire
is deleted outright.

---

## 2. System model

Hardware constants (`targets/Phantasm/Phantasm.ino`, `core/platform.h`):

| Quantity | Value | Derivation |
|---|---|---|
| RPM | 480 | 8 rev/s |
| `CANVAS_W` (W) | 288 | columns per full image (360°) |
| Column rate | 2304 Hz  | `(RPM/60)·W` |
| Column period (T0)  | ~434 µs  | `1 / 2304` |
| Revolution | 125 ms | `60 / 480` |
| Half-revolution | 62.5 ms  | one full image (two arms, 180°) |
| Frame rate | 16 fps | 2 flips/rev |
| Boards (N) | 4 | seg 0 = clock master / conductor |
| Effect duration | 120 s | = 960 revolutions |

**Rotor model — open-loop (load-bearing).** There is no hall/index/encoder
input anywhere; both drivers synthesize column timing at a *fixed* frequency
from nominal RPM (`pov_single.h`'s IntervalTimer period; the nominal
`cycles_per_half_rev` timebase constant in `pov_sync.h`). Therefore:

- "Sync" means *boards agreeing with master*, never *locking to the physical
  rotor*. Master's flywheel **is** the reference by definition.
- If the motor's true speed wanders, the whole image precesses uniformly. That
  is acceptable because every segment precesses together → still coherent.
- Absolute angular stability (image pinned to physical rotation) is **out of
  scope**; it would require a rotor index into master. See §13.

**Content clock — frame-counter, not wall-clock (load-bearing, good news).**
On-device animation advances off a per-frame counter `AnimationBase::t`,
incremented once per `step()` (`animation.h`), *not* `millis()`. So content
sync reduces to: (a) a shared `t` origin, (b) no dropped frames, (c)
deterministic RNG. For (c) the driver reseeds `hs::random()` (1337) at every
effect construction, so all boards render identical streams regardless of
boot/join history — the same per-effect determinism contract the simulator
uses. (a) is the gap the previous design left open: the effect **epoch**
(playlist advance + `t` reset) was driven by per-board `millis()`
(`show<E>(120)`'s `while (millis()-start<…)`), so boards changed effects at
different real moments; §6 replaces it with epoch-counted sequencing.

**The single wire (role in the new design):**

- **Sync wire (the only inter-board connection).** Master emits count-coded
  symbols on `PIN_FRAME_SYNC_OUT` 3 → all boards decode on `PIN_FRAME_SYNC_IN` 4.
  Carries the **boundary** marks (Layer 2, 2/rev) and the **epoch** mark
  (Layer 3, 1/effect). These same boundary marks also discipline each board's
  Layer-1 flywheel (phase snap, optional frequency trim).
- **Deleted: the column clock wire.** The former `PIN_CLOCK_OUT` 5 →
  `PIN_COLUMN_SYNC` 2 link and master's fixed-frequency PWM are removed. Master
  no longer streams a per-column clock; it runs the same flywheel as every other
  board and only emits the low-rate sync symbols. Those two pins are freed.

---

## 3. Architecture: one flywheel, three disciplined layers, one wire

```
                     sync-symbol wire  (master → all, 2/rev + 1/effect)
                                    │  phase snap  (+ optional freq trim)
                                    ▼
   ┌──────────────────────────────────────────────────────────────┐
   │  LOCAL FLYWHEEL TIMEBASE  (per board, master included)         │
   │  column position derived from a FREE-RUNNING HARDWARE CLOCK    │
   │  (cycle counter), NOT from counting timer interrupts           │
   └───────────────┬───────────────┬───────────────┬───────────────┘
        derives     │      derives  │       advances │
                    ▼               ▼                ▼
   LAYER 1: column x_     LAYER 2: boundary     LAYER 3: content t
   (which column)         → advance_display     (which frame / effect)
                    ▲               ▲                ▲
                    │ snapped       │ flipped        │ epoch-reset
                    └── boundary ───┴── boundary ────┴── epoch ──── sync wire
                        symbol          symbol           symbol
```

Every layer reads the **same** disciplined timebase, so correcting the timebase
corrects all three coherently. Each layer also has an **absolute reference**
delivered on the one wire that pulls it back if it ever drifts:

| Layer | Local advance source | Absolute reference | Resync granularity |
|---|---|---|---|
| 1 Column/phase | flywheel (time-derived) | boundary-symbol snap (+ opt. freq trim) | every half-rev (sub-column) |
| 2 Frame/flip | flywheel boundary crossing | boundary symbol (count-coded) | every half-rev |
| 3 Content | `t++` per synced flip | epoch symbol + deterministic playlist + index beacon (§6.4) | every effect; index re-verified every 16 revs |

Master's flywheel is the conductor: it free-runs and *defines* the reference;
every symbol it emits is timed from its own timebase. Downstream boards snap to
those symbols. There is no longer any board-to-board continuous clock — only the
master's flywheel as the common reference and the 2/rev + 1/effect symbols that
broadcast it.

---

## 4. Layer 1 — Column / phase: free-running flywheel, snapped by the sync wire

With the column clock wire gone, columns must be generated **locally on every
board**. The flywheel does it, and the sync wire's boundary symbols snap it back
into phase twice per revolution. The drift budget (§4.5) proves a Teensy crystal
holds sub-column alignment across the 62.5 ms between snaps, so a continuous
per-column reference buys nothing the snap doesn't already deliver.

This replaces the previous design, where every column was an interrupt
*slaved* to a shared wire (one missed edge = one dropped column, permanent ±1
until the next boundary snap). The flywheel inverts the dependency: **columns
come from a local timebase; the wire only snaps phase.**

### 4.1 The flywheel timebase — position from time, not from interrupt count (load-bearing)

This is the crux that makes everything else work. The flywheel must derive the
current column from a **free-running hardware clock** (ARM `DWT->CYCCNT` cycle
counter, or `micros()`), *not* by counting how many times its `IntervalTimer`
ISR has fired:

```
x_target = ((now_cycles - epoch_cycles) / cycles_per_column) mod W
```

Why this matters: `FastLED.show()` / the WS2801 bit-bang path masks interrupts
for windows **longer than T0** (`FastLED.show()` masks IRQs, §10). If `x_` were
incremented once per ISR fire, a masked window would coalesce several pending
timer interrupts into one fire and **lose** columns — exactly the dropped-column
bug we are eliminating. With position derived from time, the ISR that finally
runs after a mask simply reads the clock, computes the time-correct `x_target`,
and resumes there. The masked columns were not displayable anyway (the strip was
being clocked out), so jumping to the time-correct column is not just lossless —
it is the *correct* behavior. Counting ISR fires would instead resume one column
behind real angular position and smear.

The `IntervalTimer` is therefore only a *wake-up*, not the source of truth:
it paces ISR entry, but the cycle counter decides which column it is. A late,
early, or coalesced wake-up cannot inject drift.

**Wake-ups are oversampled 8× per column** (`kOversample` in
`pov_segmented.h`; the timer runs at T0/8 ≈ 54 µs). The timer grid is not
phase-locked to the flywheel — a snap shifts the flywheel's boundary instants
but not the timer — so at one wake per column, both the rendered column and
the master's first emitted pulse would lag their true instants by up to a
full, slowly beat-drifting column. Waking 8× per column bounds both
quantizations to ⅛ column, keeping the §5.2 self-censor budget meaningful
and the inter-board render skew far below a visible seam. The cost is ~18 kHz
of near-empty entries (one cycle-counter read, the 64-bit position
computation, a compare — ≈1 % CPU at 600 MHz); the pixel pack and DMA submit
still run only on a column change, at the same 2304 Hz as before.

**Wake-up contract.** Because wake-ups are advisory, the ISR must be
*idempotent* when `x_target` equals the column it last rendered (early or
beat-frequency double wake: do nothing) and *skip-tolerant* when `x_target` has
jumped (late or coalesced wake: render the time-correct column, never
back-fill the skipped ones — they were masked precisely because the strip was
busy).

**Clock source and rebase rule (load-bearing — resolves §11.2).** The clock is
`DWT->CYCCNT`: highest resolution (1.67 ns), zero cost to read. It is 32-bit at
600 MHz and wraps every **~7.16 s** — long enough to forget, short enough to
corrupt any elapsed-time computation that coasts. Rather than *handling* wrap,
make it structurally impossible: at every locally-crossed boundary the flywheel
folds its own epoch forward,

```
epoch_cycles += cycles_per_half_rev      // exact integer add, no drift
```

so `now_cycles - epoch_cycles` never exceeds ~63 ms regardless of how long the
board coasts between snaps. A snap re-bases `epoch_cycles` absolutely; the fold
keeps it fresh in between. (The same rule covers `micros()` and its 71.6-min
wrap if the cycle counter is ever unavailable.)

**Position math is 64-bit; the stored period is per-half-rev, not per-column.**
`cycles_per_column` ≈ 260,416.67 is **non-integer** — a truncated per-column
divisor bakes in a ~2.6 ppm systematic error and makes the §4.3 trim
inexpressible. Store `cycles_per_half_rev` (= 37,500,000 exactly at nominal
480 RPM) as the single, optionally-trimmed timebase constant and compute

```
x_target = (x_boundary + ((now_cycles - epoch_cycles) · (W/2))
                          / cycles_per_half_rev) mod W
```

with a 64-bit intermediate (the product peaks ≈ 5.4 × 10⁹). One long multiply
and divide per column ISR at 2304 Hz — negligible on the M7.

### 4.2 Boundary-snap discipline (baseline)

Each boundary symbol (2/rev) names an absolute column (`x==0` or `x==W/2`,
§5.2). On decode — and acceptance through the §5.3 gate — the board re-bases
the flywheel so `x_` equals that boundary,
compensated for columns elapsed during the decode window (§5.2). Between snaps
the flywheel free-runs at *its own* nominal `T0` (its own crystal). The phase
error this accumulates over one half-revolution is the crystal's relative offset
times 62.5 ms — **0.006 column at a worst-case 40 ppm** (§4.5) — and the next
snap zeroes it.

No PI loop, no per-column phase math, no tuning. A free-running flywheel plus a
hard snap twice per revolution is the entire baseline, and it is already
sub-column.

### 4.3 Optional frequency trim (refinement, not required for correctness)

The snap corrects *phase*; it leaves a ~0.006-col sawtooth seam at each boundary
(the accumulated inter-snap drift, reset each half-rev). If that seam ever proves
visible — it will not until frequency error exceeds ~0.7 % (≈100× a Teensy
crystal, §4.5) — a board can additionally trim its column period to match
master's actual frequency, learned from the *interval between consecutive
boundary symbols* measured on its own cycle counter:

```
measured_half_rev = t_boundary_k - t_boundary_{k-1}
cycles_per_column ← (1-α)·cycles_per_column + α·(measured_half_rev / (W/2))
```

A slow first-order trim (small `α`) suffices because the quantity being tracked
— relative crystal offset — drifts only on thermal timescales (seconds to
minutes), not per-frame. This is a smoothness upgrade layered *on top of* the
snap, not a replacement for it and not a prerequisite. Shipped snap-only
(§11.1): the implementation exposes the trim hook
(`Flywheel::set_cycles_per_half_rev`, exercised at ±40 ppm by the tests) but
no estimator.

> This is the disciplined descendant of the full DPLL that earlier drafts
> proposed. With only one wire it collapses from a fast PI phase-loop (locking
> per-column edges) to a slow scalar frequency estimate (one update per
> half-rev), because phase is already handled by the snap. Simpler, and provably
> sufficient.

### 4.4 Layer-1 behavior summary

| Event | Baseline (snap-only) | With frequency trim |
|---|---|---|
| Normal | flywheel free-runs at own T0; snapped 2/rev | period trimmed to master; snap nulls residual |
| Masked-IRQ window (`FastLED.show()`) | ISR resumes at time-correct column; no drift | same |
| 1 dropped boundary symbol | coasts ≤1 rev on own crystal (~0.01 col), re-snaps next | same, with even less coast error |
| 1 spurious symbol | count-decode + `try_flip` identity reject it | trim ignores out-of-window intervals |
| Sync wire dead | free-runs at nominal T0, precesses on own crystal | precesses on *trimmed* (last-known) frequency |
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

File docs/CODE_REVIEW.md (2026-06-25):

# Holosphere — Code Quality Review

**Scope:** the Holosphere C++ rendering engine and its host tooling — `core/`, `effects/`,
`hardware/`, `targets/` (wasm + Phantasm), `tests/`, `scripts/`, `tools/`, and the
CMake/PlatformIO/CI build system. Out of scope by request: `core/effects_legacy.h`,
`core/rotate.h`, and `targets/Holosphere/Holosphere.ino`. Third-party vendored headers
(`FastNoiseLite.h`, `inplace_function.h`) were assessed for integration only, not audited
line-by-line.

**Method:** thirteen component-scoped reviewer passes examined every in-scope file in full,
each consulting the README to place its scope in the wider architecture. Every candidate
finding was then handed to an independent skeptic that re-read the cited source before the
finding was admitted. Of 63 candidate findings, 14 were rejected at verification (intentional
designs, miscites, or misread invariants) and are not listed here. The 49 confirmed findings
below skew heavily toward *latent* and *documentation* issues — there is no crash, leak, or
race reachable on the shipping configuration.

---

## Overall grade: **A−**

Holosphere is a mature, unusually disciplined embedded-graphics codebase. It pairs a genuinely
elegant compile-time-resolution architecture with an exacting safety culture (fail-fast
`HS_CHECK` on cold seams, explicit `Arena&` threading, host/device bit-parity treated as an
invariant) and documentation that is among the best seen in a hobby-or-professional engine of
this size. The deductions are narrow and concentrated: CI *wiring* lags the (excellent) test
**infrastructure** that already exists, a handful of README/comment figures have drifted from
the code, and a few effects carry acknowledged copy-paste debt. None of these touch correctness
on the hardware that ships.

### Quality-dimension grades
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

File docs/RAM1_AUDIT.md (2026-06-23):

# RAM1 Byte-Level Audit — Teensy 4.0 FlexRAM

**Build analyzed:** `.pio/build/phantasm/firmware.elf` — the **real** phantasm config: `-Os` + newlib-nano (`libc_nano`/`libstdc++_nano`, via `tools/teensy_nano.py`) + the custom flash-routing linker script `tools/phantasm.ld`. teensy@5.0.0 / Teensyduino 1.59.0 / arm-gcc 11.3.1, all effects via `HS_EFFECT_LIST`.
**Toolchain:** `arm-none-eabi-{size,nm,readelf}` + `teensy_size` (authoritative region split).

> ⚠️ **This build overflows RAM1 by 27,680 bytes — a regression of exactly one 32 KiB FlexRAM bank from the prior +5,088 B baseline.** The committed `holosphere` env (RingSpin only) *fits* with ~31 KB headroom; the `phantasm` env (every effect compiled in) is the stressing case and is what this audit catalogs.
>
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

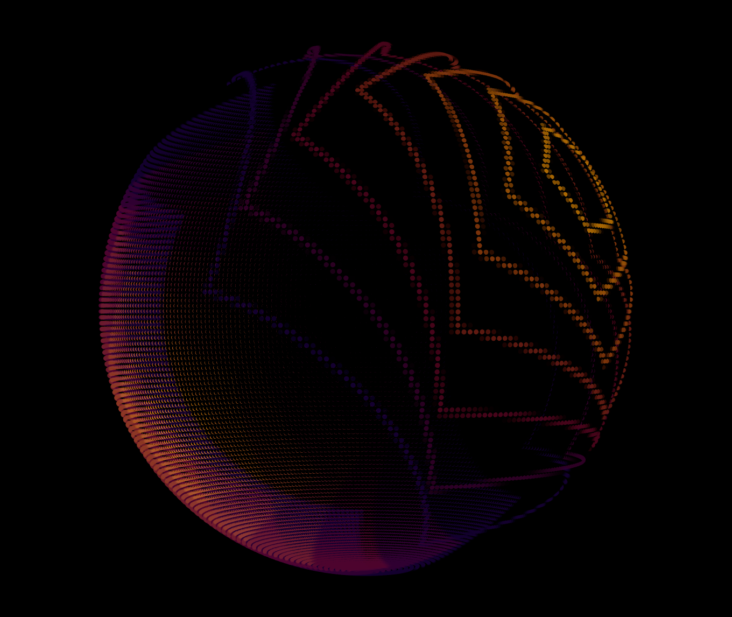
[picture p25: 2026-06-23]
docs/screenshots/ShapeShifter.png

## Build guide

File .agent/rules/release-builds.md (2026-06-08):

---
trigger: always_on
---

Always build release builds unless i ask for debug

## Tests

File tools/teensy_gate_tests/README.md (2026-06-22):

# Teensy gate fixtures & self-tests

These prove the size/layout gate (`tools/teensy_gate.py`) **fails when it should**
— a check that can never fail is worse than none (docs/teensy_ci_gate_spec.md §9.1).
They are pure host Python (`unittest`, no ARM toolchain, no PlatformIO).

```
python -m unittest discover -s tools/teensy_gate_tests
```

## Fixtures

| File | Role |
|---|---|
| `good_teensy_size.txt` | A passing `teensy_size` region report. |
| `good_readelf_syms.txt` | `readelf -s` with the real **mangled** symbol names (`_ZN6Effect8buffer_aE`, `_ZN13ReactionGraph9neighborsE`) and the internal-linkage `global_arena_block` (a LOCAL symbol). |
| `good_readelf_secs.txt` | `readelf -S` section headers (ndx → name/addr). |
| `good_size_a.txt` | `size -A` for the address-bucketing test. |
| `broken_framebuffer_dtcm_syms.txt` | `DMAMEM` dropped → `Effect::buffer_a/b` land in DTCM → framebuffers→OCRAM must fail. |
| `broken_reaction_graph_ram_syms.txt` | `const` dropped → `ReactionGraph::neighbors` in DTCM → table→FLASH must fail. |
| `broken_arena_8mb_syms.txt` | `global_arena_block` at the 8 MB `HS_TEST_BUILD` size → arena magnitude must fail. |
| `broken_missing_symbol_syms.txt` | a framebuffer renamed → "symbol not found" hard-fails (never a silent skip). |
| `broken_over_cap_teensy_size.txt` | FLASH + RAM2 over cap, DTCM headroom under floor → every region check fails. |

## ⚠ These are synthetic-but-realistic, not hardware-captured (yet)

The addresses, sizes and mangled names are hand-built to match the Teensy 4
memory map and the real source symbols, but they were **not** captured from an
actual `-O3` firmware link (no Teensy toolchain in this environment). A Phase-0
deliverable is to **replace the `good_*` fixtures with truly-captured output**
from a real build (`arm-none-eabi-size -A`, `readelf -s -S`) so the parser tests
exercise the exact toolchain formatting, then re-derive the broken variants from
that capture (spec §9.1, §13).

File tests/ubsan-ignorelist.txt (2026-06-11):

# UBSan special-case list for the native test build (-DHS_SANITIZE=ON).
#
# FastNoiseLite is vendored third-party code whose integer hashing deliberately
# relies on wrapping signed-int multiplication (e.g. `hash *= 0x27d4eb2d` and
# `i *= PrimeX` with PrimeX = 501125321). That is technically
# signed-integer-overflow UB, but it is defined two's-complement wrap on every
# target we ship and is the library's documented design — not an engine bug.
# Suppress ONLY that one check in ONLY that file; every other UBSan check stays
# active there, and all first-party code keeps full signed-overflow coverage.
[signed-integer-overflow]
src:*FastNoiseLite.h

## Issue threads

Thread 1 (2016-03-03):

pov demonstration

mkeyno, 2016-03-03:
hi buddy , do you have any video or demonstration of your code

woundedlion, 2016-03-03:
Hey, here's some videos. Hard to capture with my phone because the camera's
framerate interferes with the effect, causing flicker and other artifacts.
Suffice it to say it looks much better in person. Are you attempting
something similar?

https://www.dropbox.com/s/ppamd45tk2y6rzq/20160222_211447.mp4?dl=0

https://www.dropbox.com/s/382uwa8f63rr5in/20160222_211620.mp4?dl=0

https://www.dropbox.com/s/sw8e4pts1mf6xtu/20160222_211711.mp4?dl=0

https://www.dropbox.com/s/2oshrphxvh1eikx/20160222_211840.mp4?dl=0

https://www.dropbox.com/s/dxwprh6ebbc2su4/20160221_192401.mp4?dl=0

https://www.dropbox.com/s/kghwm038dw8doaw/20160222_211811.mp4?dl=0
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

mkeyno, 2016-06-27:
hi @woundedlion  , I'm so sorry to draw issue for my question but I really appreciated for your opinion , actually I'm trying to use fastLED lib to drive my APA102 for POV project , I've tried to implement it with ESP, but frame rate is so slow for 144 APA102 pixel,
my approach is to read pixel data from SPIFF file without closing it , but result beyond my expectation very slow even with 160Mhz clock
following is the serial output and loop code
i=0 New Image=1.bin duration=4
[frame]1076598
[frame]1043446
[frame]1044003
[frame]1043555
i=1 New Image=2.bin duration=4
[frame]1057822
[frame]1052909
[frame]1052453
i=2 New Image=3.bin duration=4
[frame]1067164
[frame]1042669
[frame]1043549
[frame]1042468
i=3 New Image=4.bin duration=4
[frame]1059210
[frame]1044297
[frame]1044701
[frame]1044550
i=4 New Image=5.bin duration=4
[frame]1059668
[frame]1042478
[frame]1043678
[frame]1043824
i=5 New Image= duration=0
FILE NOT OPEN
i=0 New Image=1.bin duration=4
[frame]1075868
[frame]1044087
[frame]1044103
[frame]1044578
i=1 New Image=2.bin duration=4
[frame]1059307
[frame]1052474
[frame]1052181
i=2 New Image=3.bin duration=4
[frame]1067527
[frame]1042757
[frame]1042843
[frame]1043076
i=3 New Image=4.bin duration=4
[frame]1058051
[frame]1045418
[frame]1046048
[frame]1045034
i=4 New Image=5.bin duration=4
[frame]1059883
[frame]1043249
[frame]1043334
[frame]1043710
i=5 New Image= duration=0
FILE NOT OPEN
i=0 New Image=1.bin duration=4

loop code
void loop()
{

if(!SHOW) server.handleClient();

webSocket.loop();

if(SHOW)
{
if( (millis()- OpenlastTime) > DURATION[image_index]*1000L )
{
FILe.close();
image_index++;
if(image_index>IMAGE_NUM) image_index=0;

   Serial.print(F(" i="));  Serial.print(image_index);
  Serial.print(F(" New Image="));  Serial.print(IMAGES[image_index]);
  Serial.print(F(" duration="));  Serial.println(DURATION[image_index]);

   FILe=SPIFFS.open("/SHOW/"+IMAGES[image_index], "r");
  if(!FILe) Serial.println("FILE NOT OPEN");
  OpenlastTime=millis();
}
if(!Start_new_round && (micros()-lastLineShow)> lineInterval)
                  {
                  int i=0,j=0;
                  byte rgb=0,r,g,b;
                  while(FILe.available()&& i< (NUM_LEDS*3))
                                                            {
                                                            byte c=FILe.read();
                                                                 if(rgb==0) r=byte(c);
                                                            else if(rgb==1) g=byte(c);
                                                            else if(rgb==2) b=byte(c);
                                                            else           { rgb=0;
                                                                             leds[j] = CRGB(r,g,b);
                                                                             j++;
                                                                             }
                                                            rgb++;    
                                                            i++;
                                                            }
                  FastLED.show(); lastLineShow=micros();                  
                  Current_imageLine++;                                
                  }

FastLED.show(); lastLineShow=micros(); }
if(Current_imageLine >= IMAGES_LINES)

{
Serial.print("[frame]"); Serial.println((micros()-lastFrameShow));
Current_imageLine = 0;
lastFrameShow=micros();
Start_new_round=false;
FILe.close();
FILe=SPIFFS.open("/SHOW/"+IMAGES[image_index], "r");
}

}

}

woundedlion, 2016-07-01:
Hi @mkeyno,
Without knowing how your POV display works, I might suggest the following:

Measure:

1) Take the total time in which you hope to draw the full image and divide by the number of columns in your display. This will give you a target duration to draw a single column.

2) Print the time in microseconds to draw a single column in your loop. This will tell you how far off from your target time you are.

3) Profile your draw loop with some logs and see where the routine is spending time.

Optimize:

1) Reading a single byte at a time from the SD card for each pixel seems potentially very slow. Can you read the whole file into an array outside of your draw loop then loop through the array in memory to draw?

2) How fast is FILE.available()? You could loop from 0 to FILE.size() - 1 instead of calling available() once for each byte. For safety, check the file size, something like assert(FILE.size() == NUM_LEDS * 3 * NUM_COLUMNS); to make sure it has all your data.

3) Get rid of i and i++ in your loop, it's not doing anything for you.

4) You are needlessly copying each byte twice. I don't know without looking at the assembly if the compiler is optimizing that away for you. Maybe just do leds[j] = CRGB(FILE.read(), FILE.read(), FILE.read());

5) Use hardware SPI if it is available on our board.

6) I'm not familiar with the ESP, its performance characteristics, memory capacity, etc. but working with the teensy 3.2 has been great. APA102 is plenty fast (as is FastLED) so your problem is likely logic or hardware. Consider better hardware?

Closed 2016-07-21.

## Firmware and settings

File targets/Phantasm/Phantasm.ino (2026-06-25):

/*
 * Required Notice: Copyright 2025 Gabriel Levy. All rights reserved.
 * Licensed under the Polyform Noncommercial License 1.0.0
 *
 * Phantasm — Multi-Teensy segmented POV display (288×144)
 *
 * Target: 4× Teensy 4.0
 * Total physical LEDs: 288 (72 per segment, 144 per arm)
 * Virtual canvas: 288×144
 *
 * Each Teensy reads its hardware ID at boot (pins 21, 22) to determine
 * which segment of the LED strip it owns.  Segment 0 is the sync master:
 * it emits count-coded symbol bursts on the single sync wire, and every
 * board (master included) generates its own columns from a local flywheel
 * timebase disciplined by those symbols.  The playlist is epoch-counted —
 * the master broadcasts an EPOCH mark when an effect's revolutions elapse
 * and all boards switch in lockstep (docs/phantasm_frame_sync_spec.md).
 *
 * Hardware ID assignment (active-low, ground to set):
 *   ID 0: both floating  — arm A outer (sync master)
 *   ID 1: pin 21 grounded — arm A inner
 *   ID 2: pin 22 grounded — arm B outer
 *   ID 3: both grounded   — arm B inner
 */

// Select the DMA HD107S output path. Must precede any include that pulls in
// led.h (via pov_segmented.h).
#define USE_DMA_LEDS

#include <FastLED.h>
#include <SPI.h>
#include <new> // std::nothrow — fail-fast OOM check on the POV allocation below

#include "pov_segmented.h"
#include "effects.h"

static constexpr int TOTAL_PIXELS = 288;
static constexpr int NUM_SEGMENTS = 4;
static constexpr unsigned int RPM = 480;

using POV = POVSegmented<TOTAL_PIXELS, NUM_SEGMENTS, RPM>;

namespace {
POV *g_pov;  // g_-prefixed: a bare `pov` collides with the hardware `namespace pov`

// Foreground effect constructor for one roster entry: LUTs, arenas, init.
// Called from the driver's show loop during the epoch construction window.
template <typename E> Effect *construct_effect() {
  // Eager-fill the scanline LUTs before the first frame so the flywheel ISR
  // never observes a half-filled table.
  GeometryResolution<E>::init();
  E *e = new E();
  configure_arenas_default(); // Reset before init so effects can override
  e->init();
  return e;
}

// Generated from the single-source effect roster (HS_EFFECT_LIST); the table
// order IS the playlist order, identical on all four boards (spec §6.1).
#define HS_FACTORY_ONE(name) &construct_effect<name<288, 144>>,
const POV::EffectFactory kEffectFactories[] = {
  HS_EFFECT_LIST(HS_FACTORY_ONE)
};
#undef HS_FACTORY_ONE

// Every input to the sync protocol config is a compile-time constant on this
// board, so reject an inconsistent protocol at the build instead of the boot.
// run_show()'s runtime HS_CHECK still guards any non-constexpr instantiation.
static_assert(
    pov::sync::phantasm_config(F_CPU, RPM, CANVAS_W, HS_EFFECT_COUNT).valid(),
    "Phantasm pov::sync::Config invariants violated");
} // namespace

void setup() {
  Serial.begin(9600); // baud inert on Teensy USB-CDC; initializes Serial only
  delay(1000);        // USB-CDC enumeration settle so early output isn't lost
  // nothrow new + HS_CHECK: a thrown bad_alloc has no handler on Teensy, so
  // fail-fast at the allocation site rather than null-deref in run_show().
  g_pov = new (std::nothrow) POV();
  HS_CHECK(g_pov != nullptr, "POV allocation failed (OOM)");
}

void loop() {
  // Never returns: the driver runs the epoch-synchronized show forever
  // (every effect plays for the same 960 revolutions = 120 s).
  g_pov->run_show(kEffectFactories, HS_EFFECT_COUNT);
}

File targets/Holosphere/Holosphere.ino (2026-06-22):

/*
 * Required Notice: Copyright 2025 Gabriel Levy. All rights reserved.
 * Licensed under the Polyform Noncommercial License 1.0.0
 *
 * Holosphere — Single-Teensy POV display
 *
 * Target: Teensy 4.0
 * Physical LEDs: 288 (144 per arm × 2 sides)
 * Virtual canvas: 288×144
 */
#include <FastLED.h>
#include <SPI.h>

#include "pov_single.h"
#include "effects.h"
#include "effects_legacy.h"

static constexpr int NUM_PIXELS = 288;
static constexpr unsigned int RPM = 480;

namespace {
POVDisplay<NUM_PIXELS, RPM> *g_pov;  // g_-prefixed: a bare `pov` collides with the hardware `namespace pov`
}

void setup() {
  Serial.begin(9600);
  delay(1000);
  Serial.println("Hello");
  g_pov = new POVDisplay<NUM_PIXELS, RPM>();
}

FLASHMEM static void run_show_sequence() {
  g_pov->show<RingSpin<288, 144>>(120); // 140

  //  pov->show<IslamicStars<288, 144>>(120);

  /*
  pov->show<RingSpin<288, 144>>(120); // 140
  pov->show<ShapeShifter<288, 144>>(120); //140
  pov->show<DreamBalls<288, 144>>(120); // 117
  pov->show<IslamicStars<288, 144>>(120);

  pov->show<ChaoticStrings<288, 144>>(120);0
  pov->show<Raymarch<288, 144>>(120);
  pov->show<SplineFlow<288, 144>>(120);
  pov->show<Voronoi<288, 144>>(120);
  pov->show<MobiusGrid<288, 144>>(120);
  pov->show<FlowField<288, 144>>(120);
  pov->show<MeshFeedback<288, 144>>(120);
  pov->show<BZReactionDiffusion<288, 144>>(120);
  pov->show<GSReactionDiffusion<288, 144>>(120);
  pov->show<Thrusters<288, 144>>(120);

  pov->show<MindSplatter<288, 144>>(120); //75
  pov->show<GnomonicStars<288, 144>>(120); //60
  pov->show<HankinSolids<288, 144>>(120); // 85
  pov->show<PetalFlow<288, 144>>(120); //35
  pov->show<Liquid2D<288, 144>>(120);  //85
  pov->show<Flyby<288, 144>>(120); // 85
  pov->show<Test<288, 144>>(120); // 60
  pov->show<SphericalHarmonics<288, 144>>(120);  //49
  pov->show<Comets<288, 144>>(120); //53
  pov->show<HopfFibration<288, 144>>(120); //72


  */
}

void loop() {
  Serial.println("Oh hi again");
  delay(1000);
  run_show_sequence();
}

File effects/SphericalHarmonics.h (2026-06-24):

/*
 * Required Notice: Copyright 2025 Gabriel Levy. All rights reserved.
 * LICENSE: ALL RIGHTS RESERVED. No redistribution or use without explicit
 * permission.
 */
#pragma once

#include "core/engine.h"
#include <cmath>
#include <utility>

namespace SHMath {
/**
 * @brief Factorial of n as a float.
 * @param n Non-negative integer whose factorial is computed; kept small.
 * @return n! as a float.
 * @details Float precision; large n would overflow float precision.
 */
inline float factorial(int n) {
  if (n <= 1)
    return 1.0f;
  float result = 1.0f;
  for (int i = 2; i <= n; i++)
    result *= i;
  return result;
}

/**
 * @brief Associated Legendre polynomial P_l^m(x).
 * @param l Degree (l >= 0).
 * @param m Order (0 <= m <= l).
 * @param x Argument, equal to cos(phi) with |x| <= 1.
 * @return Value of P_l^m(x).
 * @details Uses the standard upward recurrence: seed P_m^m, then P_{m+1}^m,
 * then recur in l.
 */
inline float associatedLegendre(int l, int m, float x) {
  float pmm = 1.0f;
  if (m > 0) {
    float somx2 = sqrtf(std::max(0.0f, (1.0f - x) * (1.0f + x)));
    float fact = 1.0f;
    for (int i = 1; i <= m; i++) {
      pmm *= -fact * somx2;
      fact += 2.0f;
    }
  }
  if (l == m)
    return pmm;

  float pmmp1 = x * (2.0f * m + 1.0f) * pmm;
  if (l == m + 1)
    return pmmp1;

  float pll = 0;
  for (int ll = m + 2; ll <= l; ll++) {
    pll = ((2.0f * ll - 1.0f) * x * pmmp1 - (ll + m - 1.0f) * pmm) / (ll - m);
    pmm = pmmp1;
    pmmp1 = pll;
  }
  return pll;
}

/**
 * @brief Precompute the spherical-harmonic normalization factor for (l, m).
 * @param l Degree (l >= 0).
 * @param m Order in [-l, l].
 * @return Normalization factor N, constant per shape.
 */
inline float normalization(int l, int m) {
  int absM = std::abs(m);
  float N = sqrtf(((2.0f * l + 1.0f) / (4.0f * PI_F)) *
                  (factorial(l - absM) / factorial(l + absM)));
  return (m != 0) ? sqrtf(2.0f) * N : N;
}

/**
 * @brief Evaluate a real spherical harmonic with a precomputed norm.
 * @param l Degree (l >= 0).
 * @param m Order in [-l, l]; sign selects cos/sin azimuthal factor.
 * @param theta Azimuthal angle in radians.
 * @param cos_phi Cosine of the polar angle, in [-1, 1].
 * @param N Precomputed normalization factor for (l, m).
 * @return The harmonic value.
 * @details Takes cos_phi directly to avoid a cosf(acos(x)) roundtrip.
 */
inline float sphericalHarmonic(int l, int m, float theta, float cos_phi, float N) {
  int absM = std::abs(m);
  float P = associatedLegendre(l, absM, cos_phi);
  return N * P * ((m > 0) ? fast_cosf(m * theta) : (m < 0) ? fast_sinf(absM * theta) : 1.0f);
}

/**
 * @brief Decode a flat harmonic index into its (l, m) pair.
 * @param idx Flat index where idx = l*l + l + m.
 * @return Pair {l, m} with l = floor(sqrt(idx)) and m in [-l, l].
 * @details Seeds l from a float sqrt, then snaps it to the exact integer floor:
 * sqrtf at (or just below) a perfect square can round to l-epsilon and truncate
 * to l-1, which would push m to +l — outside the level's valid [-l, l] band and
 * into the next level's order. The correction loops make l provably exact
 * (l*l <= idx < (l+1)*(l+1)), so the returned order is always valid. Cold path
 * (a few calls per frame).
 */
inline std::pair<int, int> decode_lm(int idx) {
  int l = static_cast<int>(sqrtf(static_cast<float>(idx)));
  while ((l + 1) * (l + 1) <= idx)
    ++l;
  while (l > 0 && l * l > idx)
    --l;
  return {l, idx - l * l - l};
}
} // namespace SHMath

/**
 * @brief Visualizer that paints real spherical harmonics on the unit sphere.
 * @tparam W Display width in pixels.
 * @tparam H Display height in pixels.
 * @details Continuously morphs between randomly chosen modes.
 */
template <int W, int H> class SphericalHarmonics : public Effect {
public:
  /**
   * @brief Field sampler that evaluates the (blended) harmonic at a world point.
   * @details Intentionally NOT a deforming SDF: on the unit-sphere display every
   * pixel samples r=1, so a lobe-radius distance would only modulate coverage
   * near the harmonic's nodes. We want full coverage and let the shader paint
   * the harmonic value, so distance() reports a constant "fully inside" and the
   * field value rides out through raw_dist (frag.v1).
   */
  struct HarmonicField {
    int l1, m1;
    int l2, m2;
    float blend;
    Quaternion orientation;
    float N1, N2; /**< Normalization factors, precomputed once per shape. */
    static constexpr bool is_solid = true;

    /**
     * @brief Construct a field for blending mode (l1, m1) into (l2, m2).
     * @param l1 Degree of the first harmonic.
     * @param m1 Order of the first harmonic.
     * @param l2 Degree of the second harmonic.
     * @param m2 Order of the second harmonic.
     * @param blend Morph fraction in [0, 1] from the first toward the second.
     * @param q Orientation quaternion of the shape.
     */
    HarmonicField(int l1, int m1, int l2, int m2, float blend, Quaternion q)
        : l1(l1), m1(m1), l2(l2), m2(m2), blend(blend), orientation(q),
          N1(SHMath::normalization(l1, m1)),
          N2(SHMath::normalization(l2, m2)) {}

    /**
     * @brief Vertical scan bounds for the field.
     * @tparam H_ Display height in pixels.
     * @return Full-height bounds; lobes can occupy any region, so no static
     * bounding.
     */
    template <int H_> SDF::Bounds get_vertical_bounds() const {
      return {0, H_ - 1};
    }
    /**
     * @brief Horizontal scan intervals for a given row.
     * @tparam W_scan Display width in pixels.
     * @tparam H_ Display height in pixels.
     * @tparam OutputIt Output iterator type for emitted intervals.
     * @return Always false: no horizontal interval narrowing (full-sphere scan).
     */
    template <int W_scan, int H_, typename OutputIt>
    bool get_horizontal_intervals(int, OutputIt) const {
      return false;
    }

    /**
     * @brief Convenience wrapper returning a fresh DistanceResult.
     * @param p World-space sample point.
     * @return The sampled DistanceResult for p.
     */
    SDF::DistanceResult distance(const Vector &p) const {
      SDF::DistanceResult res;
      distance<true>(p, res);
      return res;
    }

    /**
     * @brief Sample the (possibly blended) harmonic at world point p.
     * @tparam ComputeUVs Whether to compute UV coordinates (unused here).
     * @param p World-space sample point.
     * @param res Output DistanceResult; carries the field value in v1 with a
     * constant "inside" distance.
     * @details Rotates p into the shape's local frame, evaluates both modes in
     * spherical coords, and emits the field value through frag.v1.
     */
    template <bool ComputeUVs = true>
    void distance(const Vector &p, SDF::DistanceResult &res) const {
      Vector local = rotate(p, orientation.conjugate());
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

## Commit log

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2026-10-31 pullback: share modulation field input traversal (finding 35)
    Use one internal visitor for cache identities and temporal field equality.
    Keep direct selected-recipe comparisons without materializing identity copies.
    Preserve dormant defaults, unknown-source rejection and the bake-layout version.
    Independent classification tests reject mutations omitting noise seed or phase,
    selecting interference for grid, comparing enabled, or admitting unknown sources.
    ARM comparison instruction counts and zero stack use are preserved at Os/O3;
    the shipping WASM comparison body is identical.
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2026-10-31 tests: qualify gradient precision under fast-math reassociation
    Keep strict gradient and curl comparisons exact. Give fast-math API comparisons frequency- and coordinate-scaled single-precision budgets; preserve independent finite-difference and physical error oracles. Admit the input direction in the Millefiori phase oracle before evaluating its waves.
    Clang 22 -Os fast-math: noise_field 228211 assertions pass; focused gradient/curl 62541 and composed cases 146 pass. Strict gradient/curl 84333 pass. Original exact tests also pass with only -fno-associative-math added. Gradient X-sign mutation fails 9216 assertions; wrong frequency admission fails 3.
2026-10-31 tests: qualify optimized shader roundoff separately from strict parity
    Keep exact strict-mode comparisons and existing physical camera budgets.
    For -Os -ffast-math -fno-finite-math-only, qualify the unfactored AshCloud
    shader independently at 16 RGB codes, 8 premultiplied codes, 1e-5 alpha,
    and exact camera direction. Clang 22.1.8 Windows measured 10/5/8.106e-6/0
    over 1,380,096 samples; Linux CI measured 1/1/0/0. The shared-color
    identity and fallback tests remain exact.
    The lattice scalar reference measures 4.768e-7 maximum error on the full
    parameter sweep; retain bit equality in strict mode and use eight float
    epsilons in fast mode. A +0.01 circle-distance mutation yields error 2
    and is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
2026-10-31 tests: refresh MobiusGrid native fast-math trajectory references
    Retain strict and WASM references, channel tolerance 1e-3, centroid tolerance
    0.01, and the asymmetric fingerprint checks. Record native Windows and
    Linux -Os fast-math results for the current shared shader implementation.
    Compare commit 37bb56a3a and current source in the same Clang 22.1.8
    1140-frame ideal-display probe. Original-source channel totals reproduce
    the old Windows reference within 1e-8 relative; current source reproduces
    the new Windows reference within 1e-7. Early frames are byte-identical,
    then tiny roundoff grows through the animated trajectory and preset change.
    Reverting periodic.h/interpolate.h alone leaves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
2026-10-31 tests: bound fused alpha reassociation in fast-math
    Keep strict alpha and all color comparisons exact; bound fast-math alpha roundoff by four float epsilons relative to its magnitude. Focused strict and CI-fastmath runs each pass 249600 assertions. A production overlay increasing fused coverage by one percent fails 62400 assertions.
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2026-11-01 pullback: preserve composed resource template identities
    Append Twist after existing resource kinds so provider specializations retain
    their original integral identities. Pinned Clang 22.1.8 LLVM probes against
    468753e7d restore all 390 MobiusGrid function symbols and normalized bodies.
    Keep every render golden, fingerprint tolerance and trajectory unchanged.
    Qualify Millefiori and AshCloud document parity at two RGB LSBs only under
    fast-math, preserving strict-mode one-LSB and alpha bounds. The old source
    already reproduces Millefiori's four two-LSB failures; traced field roundoff
    is 6.08e-6 after direction differences below 1.8e-7 per component. Injecting
    three LSBs causes 28 failures and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
2026-11-01 DreamBalls: tighten Bhaskara orbit motion bounds
    Bound the normalized fast-trig path with certified phase speed and
    curvature limits, preserving the Bhaskara evaluator. Mark third derivatives
    unbounded across folds and retain zero bounds for stationary paths.
    Document a reproducible exact rational certificate. Exercise independent
    normalized derivatives, float chord captures, and midpoint work. The ideal
    circle curvature mutation fails the bounds tests; restoring the previous
    loose curvature fails the midpoint-work assertions.
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2026-11-03 pullback: share the cached color base across runtime modulation sources
    Authored modulation providers resolve their source and evaluation at run
    time, so the shared column-phase tail now dispatches on the live recipe:
    displacement, direct noise and direct smooth-grid sources evaluate once
    per pixel instead of once per temporal endpoint. A cached OKLab palette
    base also serves columns whose color endpoints coincide, so static and
    interval frames shade through one path.
    The periodic affine warp measures its repeat-relative displacement with
    centered remainders instead of libm remainderf and hypotf, affine frames
    multiply by prepared reciprocal scales, and S2 projection divides once
    per sample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
2026-11-04 pullback: author the twist lens axis with phi and lambda controls
    Axis Phi and Axis Lambda place the twist axis; Speed and Drift rotate it
    from there. Both default to zero, so existing presets keep their axis.
    GridWorms' parameter snapshot grows by the two fields and moves to schema
    version 2.
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2026-11-04 sources: remove Spherical Rings, Escape Fractal and Spherical Noise
    Delete sample.spherical-rings.v3, sample.fractal.v2 and
    sample.spherical-noise.v3 with their parameter families, source policies,
    pattern kernels, resource clocks, runtime snapshot kind, snapshot codec
    entries, catalog rows and tests. No shipping effect or promoted pattern
    used them. The operator table drops from 48 to 45 entries and the
    generated catalogs and assignment fixture are regenerated.
2026-11-04 effects: promote LiquidWindows and GridWarp
    Both shaders displace the sphere by a scalar-potential flow before an
    equirectangular grid: LiquidWindows folds it with a dodecahedral
    poloidal term, GridWarp warps a wandering camera with a toroidal
    degree-8, order-4 mode and adds baked-cube noise hue. Their fixed
    specs bind the potential surface with path tracking for displacement
    hue; the documents drop the colorize fields their cycling palette
    gates off. Both stay out of the Phantasm playlist until they render
    within the 62.5 ms display window.
2026-11-04 pullback: resolve affine translation from the next source's lattice
    warp.affine.v4 ("Affine Warp") replaces warp.affine.v3 and
    warp.affine-periodic.v1 with one parameter family, Warp::AffineParams:
    speed, rotation rate, Repeat Windings A/B, scale, shear, Repeat Cells and a
    Fallback Lattice Period.
    A planar source reports its translation symmetry as a TranslationLattice
    (core/render/pullback/translation_lattice.h); sample.lattice.v2 reports the
    square lattice of period 1 / Lattice Cell Scale. Each phase turn translates
    round(windings) basis vectors of the immediately next stage's lattice times
    round(Repeat Cells). Path length is the displacement reduced to its closest
    vector modulo that repe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
2026-11-04 effects: promote Iridescence
    A dodecahedral poloidal potential flow folds an equirectangular grid
    beneath the procedural embers palette, a baked-noise lightness lift and
    baked noise hue. Its fixed spec takes the authored color provider for the
    named palette, and the preset generator now emits colorize selections
    for any spec that uses that provider. It stays out of the Phantasm
    playlist until it renders within the 62.5 ms display window.
2026-11-04 pullback: share cube taps across the column phase tail
    The phase tail carries per-pixel scratch, so consecutive baked-noise
    layers resolve the sample direction's cube coordinates once. Each layer
    runs out of line from cached flash instead of inlining into its caller,
    which kept flash shaders compact without adding ITCM copies.
2026-11-04 math: fuse harmonic gradient terms and skip silent potential terms
    The spherical-harmonic gradient evaluates its Legendre value and slope in
    one Horner pass, and zero-amplitude potential terms skip their trig and
    normalization when a field is prepared for each column.
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2026-11-04 sources: merge Lattice into Tessellation
    sample.tessellation.v3 ("Tessellation") replaces sample.lattice.v2 and
    sample.tessellation.v2 with one static cell source. Kind selects square,
    hexagonal or triangular cells on a lattice of period 1 / Cell Scale; Fill
    selects Cells, a primitive centred on each cell blended from a circle to the
    cell's polygon (exact signed distance, rounded past the corners), or Edges,
    an antialiased band along the cell edges. Lengths are in cell units, one
    inscribed diameter. The source has no clocks; rotation comes from the affine
    warp.
    Hexagonal cells and triangle vertices sit on the hexagonal lattice with basis
    (p, 0), (p/2, p*sqrt(3)/2); the operator and the comp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
2026-11-04 sources: move rigid source motion to the affine warp
    Planar sources keep only motion that changes their shape; an affine warp
    placed immediately before a source supplies its translation and rotation.
    sample.grid.v4 ("Grid") drops Drift and Source Angle Speed. Speed advances
    one coupling phase phi: sin(x + c sin(y + phi)) cos(y + c cos(x - phi)),
    blended toward the static direct product sin(x) cos(y); zero complexity or a
    pattern mix of 1 draws the direct product. The grid reports the square
    translation lattice of period 2pi / Pattern Freq
    (RECTANGULAR_TRANSLATION_LATTICE), valid inside the source's argument clamp.
    sample.spiral.v3 ("Spiral") is the stationary sin(r - arms * azimuth) with
    a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
2026-11-04 math: cut the polyhedral atlas kernel to one divide and one square root
    Area correction now derives from the face cosine the face pick already
    yields: the equal-area radius over the central radius is
    cos * sqrt(2 / (1 + cos)), folded with the central divide into one
    reciprocal, so a corrected sample costs one divide and one square root
    instead of two of each.
    Centrally symmetric solids pick their face from half the selectors by
    absolute value, every tile tests a compile-time side count (short faces
    pad with sides that never bind), and side lines are stored relative to
    the tile center.
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2026-11-04 pullback: keep the palette cache through column-control Lerps
    The interval palette LAB/RGB cache was admitted only when the two frame
    endpoints had equal color families. A preset Lerp moves mapping frequency,
    mapping curve, opacity or brightness every frame, so every pixel of the
    transition took the two-palette RGB blend and OKLab/gamut finish.
    Both palette endpoints read those controls from the sampled column frame,
    in the cached and canonical paths alike; only the endpoint palettes differ.
    `Color::same_palette_controls` now compares every color field except the
    ones `assign_column_controls` names (mapping frequency/phase, oscillation,
    brightness bounds, opacity, mapping curve, brightness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
2026-11-04 pullback: compile only the non-identity parts of each affine stage
    Each composed affine stage now names a `Warp::AffineForm` in its
    `WarpPolicyFor`: the rotation, translation and scale-shear parts it
    evaluates. `affine_coords` and the affine `prepare` drop omitted parts with
    `if constexpr`, so a translation-only stage skips the per-column cosf/sinf
    and the per-sample rotation, a rotation-only stage skips the translation,
    and no shipping stage pays for the scale-shear cycle. An untracked stage
    also skips the repeat-lattice reduction. A stage without a form stays
    general, and the chain interpreter keeps the general form.
    The promoted-document check requires every composed affine form to equal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
2026-11-04 pullback: register only the sliders an affine stage's form reads
    A composed affine stage that compiles out a part no longer registers the
    sliders for it. The AffineParams fields carry per-resource gates, which
    `field_gate_open<Spec, Resource>` evaluates against the form of the stage
    keyed like the resource: rotation rate with ROTATES, windings with
    TRANSLATES, scale and shear with SCALES_SHEARS, Repeat Cells with
    TRANSLATES or with path length tracked over the next stage's lattice, and
    Fallback Lattice Period with TRANSLATES where the next stage reports no
    lattice. The warp speed slider is registered unless the stage evaluates no
    part. Slider count, arena name bytes and registration share th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
2026-11-05 phantasm: place Hopf trail hot code in one cache way
    HopfFibration's timed trail draw runs from flash: render_timed_trails, the
    steady-edge point route and the steady-lattice test run per edge. Code growth
    in the shared column-chain and cull paths moved these functions so up to four
    or five hot lines map to one set of the 2-way instruction cache. The profile
    image's per-edge loop then missed in the cache on every edge. Host work counters
    match dc7b5df21 for every frame of the capture.
    Place them contiguously in a window bounded by one 16 KiB cache way, so each
    set holds at most one line of it. RAM1 code is unchanged; the ITCM symbol list
    of the phantasm image matches 48d808d04.
    Profile cap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
2026-11-05 pullback: sample directional sine modulation at the column phase
    The column phase tail admitted displacement, noise and smooth-grid
    modulation sources but not a directional sine, so GridWorms never reached
    the shared cached color base. Every frame whose palette changed shaded both
    palette endpoints, modulated each, blended them and finished the result
    through OKLab and gamut mapping per pixel, while the interval LAB and RGB
    palette caches it baked every frame went unread.
    A directional sine with an unchanged recipe is now phase compatible: the
    provider interpolates the wave phase along the shortest arc at the column
    time, and the phase tail samples it once against the cached interval base.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
2026-11-05 pullback: sample both cubes for stationary phase endpoints again
    The single-cube selection saved about 1.1 ms on stationary-noise effects but
    cost 2 KiB of flash and measured slightly slower on moving-noise effects.
    This reverts commit 1758aa8df.
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2026-11-05 phantasm: gate instruction-cache set occupancy per effect
    After the final link, tools/hot_layout.py re-derives every effect's hot set
    from the linked image and counts its gated lines per instruction-cache set. The
    build fails when an effect holds more than two lines in any set, or when an
    expected effect has no code in the image: the Phantasm playlist for Phantasm
    images, HS_PROFILE_TARGET for profile images. The report names each failing
    effect and the functions in its worst set, and is written beside the firmware.
    The gate runs in every phantasm.ld build, so the teensy-size job enforces it,
    and CI uploads the report with the firmware. On dc2954193's hand-written layout
    38 of the 39 playli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
2026-11-05 pullback: remove unused retained endpoint argument (finding 88)
    Drop the always-false run_stage argument and its dead condition; retain endpoint selection in the color tail.
    Two reversed-order device A/B pairs measured +41.53/+41.33 us per Millefiori frame (~0.088% of 47.13 ms). Its shade symbol grows 8 ITCM bytes while total RAM1 code stays unchanged. The user explicitly approved this measured tradeoff.
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2026-11-05 tests: refresh the stable-root ShapeShifter pin (finding 6)
    The original6e rendering matches the old fingerprint. The corrected descending-root formula alone produces the new96x20 hash and one additional green unit; the same record persists through116. Refresh only this hash and its RGB/row/column folds. The complete column-time parity case changes from35pass/1fail to36pass/0fail, with other recorded outputs unchanged.
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2026-11-06 particles: share lifetime conversion across storage policies (finding 229)
    Use one forced-inline lifetime conversion for trail and point particles. Both storage policies retain finite clamping and immediate expiry for non-finite values.
    Validation: animation Debug and optimized suites pass26833 assertions each; non-finite survival mutation fails all6 intended cases. Phantasm gates pass with identical executable sections and unchanged memory; only8 diagnostic source-line bytes differ.
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2026-11-06 effects: skip Hankin strap bakes during column-time blending (finding 92)
    Alias strap LUTs to their star entries when per-column shading reads crossfade endpoints. Keep flat and paused pre-blends, and pass the policy explicitly to fixed-frame test consumers. Test endpoint aliases and scratch use across the opening window.
    Native mesh-effect4296 assertions and all five Conway modules pass. Same-COM4 full-cycle mean−5.081us, peak31.699→31.606ms, no spills; tiny positive groups remain within observed block variation. Single-pair comparison includes layout effects. RAM budgets unchanged; FLASHcode+48B.
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2026-11-07 tests: consolidate review regression coverage and test tooling
    f602818f3 tests: strengthen regression checks and test tooling (findings 18–565)
    ec2ce69a0 cmake: declare the WASM render-golden test capabilities directly (finding 246)
    45d428338 tests: consolidate pending review coverage and fixtures (findings 320-420)
    dad261074 tests: consolidate numerical, renderer, hardware, and tooling review fixes
    70a56e83b test: pin verified color weighting and pose history bounds
2026-11-07 style: consolidate review naming, constants, and equivalent expressions
    9f324697d style: simplify equivalent expressions and declaration layout
    39cefa385 modulation: share the serialized recipe and clock version (finding 234)
    4858ce999 mesh: use the shared Hankin vertex limit (finding 79)
    dd97c0d7a pullback: bound authored palette mode by its selector table (finding 116)
    77a156001 ripple: share the negligible amplitude cutoff (finding 140)
    c628a087f ray: share the sphere-trace overrelaxation default (finding 150)
    8219e25c7 palette bindings: share the bake and view dimensions (finding 236)
    0c21e5428 mesh: share the baked relaxation builder advance (finding 81)
    6a4ce7ed3 choreography: name tra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
2026-11-08 hyper_lattice: assert shade properties instead of recorded tables
    Replace the shade-signature tables with properties: misses shade to zero,
    alpha stays in [0, 1] and channels within the depth palette, a lattice
    symmetry applied to the view direction and camera pose leaves the sample
    unchanged, and the specialized 4D-slice shade matches the general one.
    Replace the instantaneous render pins with a lit check at both
    resolutions plus a segment-clip check at 96x20; each render prints its
    hash under HS_PRINT_RENDER_HASHES.
2026-11-08 reaction_diffusion: assert untimed render properties instead of goldens
    Replace the BZ and GS untimed render goldens with properties: a banded
    clip equals the full render inside the band, and the full and shipped-size
    renders are lit. Each render prints its hash under HS_PRINT_RENDER_HASHES.
    Concentration bounds stay covered by the existing white-box clamp and
    boundedness cases.
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2026-11-08 tests: assert inverse-renderer properties instead of pixel goldens
    Replace the SphericalHarmonics, ShaderChain and MobiusGrid instantaneous
    pixel goldens, with their strict, fast-math, Linux and WASM references,
    by properties: renders are lit, and frames drawn under a clip schedule
    equal the unclipped render inside each clip. MobiusGrid's lens also stays
    on its eased phase through the Lerp departure, and SphericalHarmonics
    adds a segment-clip check at 288x144. Each render prints its hash under
    HS_PRINT_RENDER_HASHES.
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2026-11-08 shader_chain: replace the native catalog golden with catalog properties
    Delete tests/data/shader_chain_catalog.json, its generator and the
    regenerate_shader_chain_catalog target. The catalog is exported in-process
    and checked for unique versioned operator ids, numeric defaults inside
    their ranges, topology defaults among their values, block layouts equal
    to the operator table's (and, at compile time, to each model's
    sizeof/alignof), a full chain's fixed overhead and every operator's
    footprint within the arena, and equality with the wasm32 catalog
    (scripts/engine_catalog.json) outside block layouts, where only
    pointer-bearing blocks may widen.
    The native/wasm pairing moves from shader_workbe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
2026-11-08 composed: replace the derivation reach table with a compile-time derivation check
    Delete DERIVATION_REACH, its count pins and the document tests that
    mirrored it value by value. A static_assert now walks OperatorModels and
    requires every source and warp operator family, and every displacement
    lens family, to derive a composed policy; tessellation is checked for
    each fixed kind and fill, and chain families that extend a composed
    family with catalog-only topology are checked through that family. Lens
    operators whose policies a Spec names directly are listed. Five
    representative is_same checks of exact specializations remain.
2026-11-08 composed: select every surface policy by family
    SurfacePolicyFor takes the surface resource key and maps the authored
    curl and direct families to ConfiguredCurl and ConfiguredDirect, matching
    the authored warps, plus the burst ripple, potential, Rossby-Haurwitz and
    symmetric families. GridWarp, Iridescence, LiquidWindows, AshCloud and
    Millefiori declare their potential and ripple surfaces (and Millefiori its
    vortex warp) through the selectors; every selected type is unchanged.
    The derivation check reaches the curl and direct operators through their
    own families and no longer lists the displacement operators as
    Spec-named.
2026-11-08 composed: select lens policies by family
    LensPolicyFor maps each lens parameter family to its policy, mirroring
    the source, warp and surface selectors: FixedGlitchParams and
    FixedKaleidoscopeParams<Symmetry, Fold> to the fixed folds, GlitchParams
    and KaleidoscopeParams to ConfiguredGlitch and ConfiguredKaleidoscope over
    KeyedLensProvider, TwistLensParams to AnimatedTwist and
    MobiusGeneratorParams to MobiusGenerator. Every composed Spec now declares
    its lenses by family; each selected type is unchanged.
    Millefiori's tetrahedral fold of a dodecahedral-chamber direction moves
    into core as TetrahedralFromDodecahedralKaleidoscope, selected by
    KaleidoscopeFold::FROM_DODECAHEDRAL_CHAMBER.
    The der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
2026-11-08 tests: derive composed-effect expectations from named constants and properties
    Chamber chart, palette RGB reuse and Millefiori ripple ages follow their
    named constants; MobiusGrid exports its lens period; AshCloud's shared
    path is a lower bound; document modulation edits run on a fixed-topology
    probe. Drop GridWorms preset value pins, the legacy Mobius coefficients,
    the HexOil/AlienCore affine-form and lens-placement pins covered by the
    roster slider and document-pipeline checks.
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

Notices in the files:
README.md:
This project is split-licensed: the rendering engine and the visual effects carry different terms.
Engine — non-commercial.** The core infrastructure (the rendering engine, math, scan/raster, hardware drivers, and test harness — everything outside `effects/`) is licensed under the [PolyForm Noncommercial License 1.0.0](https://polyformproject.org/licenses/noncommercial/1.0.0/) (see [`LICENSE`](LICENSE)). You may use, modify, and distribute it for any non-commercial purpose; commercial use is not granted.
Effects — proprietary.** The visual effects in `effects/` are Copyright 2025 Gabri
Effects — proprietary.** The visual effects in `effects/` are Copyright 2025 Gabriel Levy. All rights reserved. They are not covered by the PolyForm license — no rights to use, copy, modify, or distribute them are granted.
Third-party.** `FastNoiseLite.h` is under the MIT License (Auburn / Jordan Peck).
